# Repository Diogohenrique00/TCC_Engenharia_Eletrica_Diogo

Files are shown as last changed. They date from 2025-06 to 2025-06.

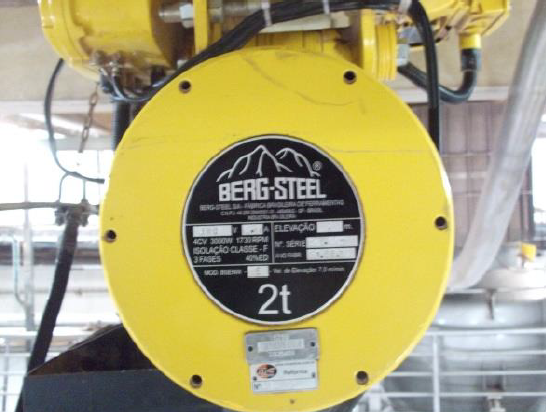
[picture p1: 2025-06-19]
FOTOS TALHAS/Captura de tela 2025-03-13 082055.png

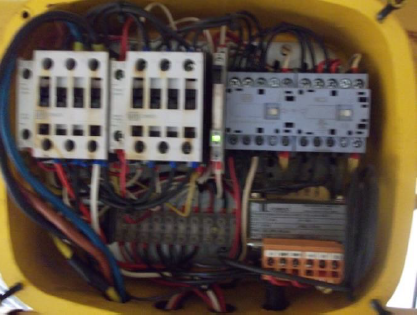
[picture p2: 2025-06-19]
FOTOS TALHAS/Captura de tela 2025-03-13 082145.png

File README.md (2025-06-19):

# ⚡ Instalações de Painéis Elétricos Para Adequação à NR-12 em Equipamentos de elevação de Cargas

Este repositório apresenta um estudo de caso sobre a adequação de painéis elétricos de comando em equipamentos de elevação de cargas, com base nas exigências da NR-12 na indústria alimentícia. A pesquisa teve como objetivo identificar não conformidades no sistema de comando de uma talha elétrica, descrever as intervenções técnicas realizadas e avaliar os indicadores obtidos após a implementação das melhorias.
_____________________________________________________________________________________________________________________________________________________________________________________________________________________
## 📌 Objetivos do Projeto

✅ Analisar o processo de adequação de um equipamento de elevação de cargas à NR-12, com ênfase na instalação e operação de painéis elétricos normatizados e seguros;  
✅ Verificar as principais não conformidades encontradas no sistema de comando e controle anterior;                                                                    
✅ Descrever os procedimentos técnicos e normativos utilizados na adequação dos painéis;                                                                               
✅ Avaliar os indicadores com a implementação, considerando ganhos em segurança, eficiência e desempenho técnico.                                                      
_______________________________________________________________________________________________________________________________________________________________________
## 🔍 Conteúdo Técnico

O trabalho abrange todas as etapas necessárias para garantir a segurança na utilização de máquinas e equipamentos, especificamente em uma talha elétrica:

## 🔌 Dimensionamento Elétrico

- Cálculos elétricos dos motores utilizados;
- Correção de fator por agrupamento e temperatura, conforme a NBR 5410;
- Escolha do disjuntor motor adequado para o projeto.

## ⚠️ Escolha dos dispositivos de segurança, conforme à NR-12

- Relé de segurança;
- Relé falta de fase;
- Disjuntor motor;
- Contator de segurança;
- Fonte chaveada;
- Botão de emergência;
- Chave seccionadora geral.
_____________________________________________________________________________________________________________________________________________________________________________________________________________________
## ⚙️ Descrição do equipamento de elevação de carga

A talha elétrica utilizada no processo é do tipo trifásica 380V, com capacidade nominal de 2 toneladas, acionada por um motor elétrico trifásico 4cv (deslocamento vertical) e um motor elétrico trifásico 0,5cv (locomoção transversal) e controlada por botoeiras pendentes.
_____________________________________________________________________________________________________________________________________________________________________________________________________________________
## 🛠️ Ferramentas Utilizadas

- AutoCAD (layout do painel);
- Excel (cálculos).
_____________________________________________________________________________________________________________________________________________________________________________________________________________________
## 🏫 Instituição
Centro Universitário da Fundação Hermínio Ometto (FHO) – Araras/SP                                                                                                                                                                      
Curso: Engenharia Elétrica                                                                                                                                                                                            
Período de entrega: Junho de 2025
_____________________________________________________________________________________________________________________________________________________________________________________________________________________
## ⚠️ Restrições de Uso

Este projeto destina-se exclusivamente a fins didáticos e não deve ser utilizado em aplicações reais sem validação técnica profissional. Qualquer uso comercial, seja direto ou indireto, é proibido sem autorização expressa do autor. Para outras finalidades ou obrigações de uso que não se enquadrem nessas condições, por favor, entre em contato com o autor.
_____________________________________________________________________________________________________________________________________________________________________________________________________________________
## ✉️ Contato

- Diogo Henrique de Camargo
- diogocamargo91@gmail.com
- https://www.linkedin.com/in/diogo-henrique-a6a4a41b4/

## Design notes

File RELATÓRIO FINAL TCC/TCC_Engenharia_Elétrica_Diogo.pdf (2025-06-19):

INSTALAÇÕES DE PAINÉIS ELÉTRICOS PARA ADEQUAÇÃO À NR-12 EM

EQUIPAMENTOS DE ELEVAÇÃO DE CARGAS EM UMA INDÚSTRIA

ALIMENTÍCIA

Diogo Henrique de Camargo (FHO) diogocamargo@alunos.fho.edu.br Daniel Augusto Pagi Ferreira (FHO) danielferreira@fho.edu.br

Resumo

Este trabalho apresenta um estudo de caso sobre a adequação de painéis elétricos de comando em equipamentos de elevação de cargas, com base nas exigências da NR-12 na indústria alimentícia. A pesquisa teve como objetivo identificar não conformidades no sistema de comando de uma talha elétrica, descrever as intervenções técnicas realizadas e avaliar os indicadores obtidos após a implementação das melhorias. A metodologia adotada foi de natureza qualitativa e aplicada, com abordagem técnico-descritiva, estruturada a partir de levantamento in loco, análise documental, aplicação de checklists normativos e coleta de dados operacionais. Os dispositivos selecionados para o novo painel incluíram relé de segurança, chave seccionadora geral, botão de emergência, sensores magnéticos de fim de curso, fonte chaveada, contator de segurança e disjuntor motor dimensionado conforme a NBR 5410. Os indicadores demonstraram uma eliminação total das falhas elétricas e um aumento de 75% na eficiência da parada de emergência, além de diminuição de 60% no tempo de manutenção corretiva. A adequação também contribuiu para a melhoria da cultura de segurança e preparação da empresa para futuras auditorias e fiscalizações.

Palavras-chave: NR-12; Segurança elétrica; Painel elétrico; Equipamentos de elevação.

### 1. Introdução

A segurança em ambientes industriais constitui um dos principais pilares da engenharia

moderna, especialmente em setores com alta complexidade operacional, como é o caso da

indústria alimentícia. O avanço das tecnologias produtivas e a crescente automatização dos

processos tornaram indispensáveis as ações preventivas voltadas à integridade física dos

trabalhadores. De acordo com dados do Ministério do Trabalho e Emprego, cerca de 25% dos

acidentes mais graves em ambientes industriais no Brasil estão diretamente associados à

utilização de máquinas sem proteção adequada, com falhas de operação e ausência de dispositivos de segurança elétrica e mecânica (SANTOS JÚNIOR; ZANGIROLAMI, 2020).

Nesse cenário, a Norma Regulamentadora nº 12 (NR-12), publicada pela Portaria nº 3.214/1978

e atualizada periodicamente (última versão data de 2022), tem papel central na regulamentação

da segurança do trabalho em máquinas e equipamentos. Seu conteúdo estabelece critérios

técnicos e diretrizes para a instalação, operação, manutenção e desativação de sistemas

mecânicos e elétricos industriais. Desde as reformulações mais significativas realizadas a partir de 2010, a NR-12 passou a adotar uma abordagem preventiva e sistêmica, exigindo a análise

de riscos e a implementação de dispositivos de segurança interligados aos sistemas de comando

(FERREIRA; SOUZA, 2021).
É importante destacar que a NR-12 atua de forma articulada com outras normas técnicas

igualmente essenciais, como a NR-10 — voltada à segurança em instalações elétricas — e a

NBR 5410, que regula a execução de instalações elétricas de baixa tensão. Essa

interdependência normativa exige que profissionais da engenharia tenham domínio transversal

das exigências legais e técnicas, garantindo que o projeto e a instalação de painéis elétricos, por

exemplo, respeitem critérios de proteção contra choques, sobrecargas, curtos-circuitos,

acessibilidade e controle ergonômico (COSTA et al., 2022).

No caso específico da indústria alimentícia, a aplicação da NR-12 apresenta desafios adicionais.

As condições ambientais a que os equipamentos estão submetidos — como presença de

umidade, vapores, poeiras orgânicas e agentes de limpeza — impõem requisitos mais rigorosos

de vedação, resistência e facilidade de higienização. Equipamentos como talhas elétricas e

pontes rolantes, amplamente utilizados na movimentação interna de insumos e produtos,

precisam ser dotados de painéis elétricos que assegurem tanto o funcionamento automatizado

quanto a interrupção imediata em situações de risco (FERNANDES et al., 2024).

A relevância da instalação adequada de painéis elétricos para a segurança dos operadores é

incontestável. Esses dispositivos não apenas comandam o funcionamento do equipamento, mas

integram sistemas de proteção que detectam falhas, bloqueiam movimentos indevidos e evitam

o acionamento em condições inseguras. botões de emergência (figura 2), chaves seletoras, relés

de segurança, fontes chaveadas, sensores magnéticos (figura 1) e dispositivos de

intertravamento formam um conjunto que, quando corretamente dimensionado e instalado,

reduz consideravelmente os riscos de acidentes, paradas não programadas e falhas operacionais

(DRUMOND, 2021; LAMB, 2015).

Figura 1 – Sensor magnético

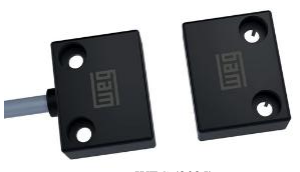
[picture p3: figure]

Fonte: WEG (2025)
Conforme mostra a Figura 2, o botão de parada de emergência é um dos dispositivos

obrigatórios exigidos pela NR-12. Os relés de segurança conforme mostra a figura 3, são previstos para montagem em quadros de comando. Eles servem para a análise segura dos

terminais de ruptura positiva de chaves magnéticas fim de curso, sensores indutivos,

capacitivos, ópticos e contatos de botões de emergência. Quando recebem um sinal elétrico

fechado entre os canais S11-S12 e/ou S21-S22, os contatos de saída 13-14, 23-24 e 33-34

fecham, mediante a atuação da entrada do botão de rearme Y1/Y2. Ao abrir as entradas S11-

S12 e/ou S21-S22, os contatos 13-14, 23-24 e 33-34 abrem, inibindo o funcionamento do

circuito elétrico (FAQUIM, 2015). Esses dispositivos são essenciais para garantir que a energia

seja interrompida de forma imediata e controlada em situações de emergência, atuando como

última barreira contra falhas críticas no sistema.

Figura 2 – Botão de emergência conforme NR-12

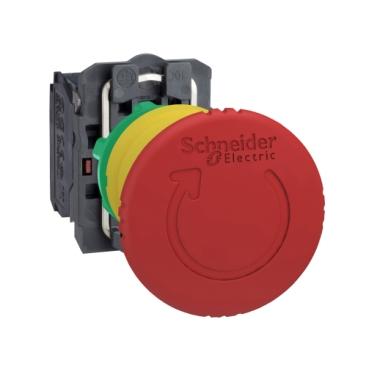
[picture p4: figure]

Fonte: Schneider (2025)

Figura 3 – Relé de segurança parada de emergência

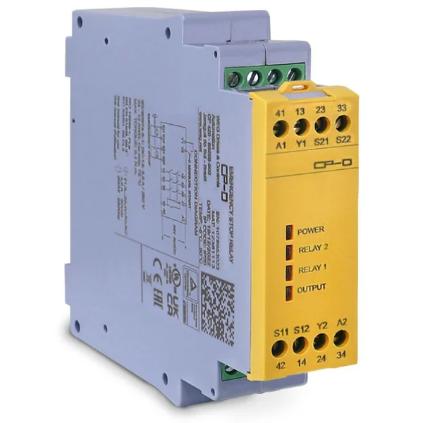
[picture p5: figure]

Fonte: WEG (2025)

No entanto, é comum observar resistência de gestores industriais à implementação plena das

normas técnicas. A percepção de que a adequação representa um custo adicional, e não um

investimento em segurança e eficiência, ainda persiste em diversas organizações. Esse

obstáculo cultural muitas vezes impede a adoção de medidas simples, porém eficazes, como o uso de sistemas de controle em malha fechada, a instalação de botoeiras com rearme em pontos

estratégicos e a atualização dos componentes obsoletos dos painéis (MOURA et al., 2022).

Neste trabalho, busca-se apresentar um estudo de caso real realizado em uma indústria

alimentícia de grande porte, localizada no interior do estado de São Paulo, que enfrentava sérios

problemas de segurança e operacionalidade em seus sistemas de elevação de cargas. O

equipamento em questão — uma talha elétrica utilizada no transporte de insumos entre setores

produtivos — operava sem dispositivos normatizados de controle e proteção, colocando em

risco os trabalhadores e comprometendo a regularidade das atividades produtivas. Com a

intervenção técnica conduzida, foram instalados painéis elétricos de comando e proteção

totalmente compatíveis com as exigências da NR-12, NR-10 e NBR 5410.

A análise do caso permitiu identificar, inicialmente, as principais não conformidades presentes

no sistema antigo, como a inexistência de botão de parada de emergência acessível, ausência

de relé falta de fase, relé de segurança, instalação elétrica desorganizada e fiação exposta. Além

disso, o painel apresentava falhas de vedação e estava posicionado em local de difícil acesso,

contrariando as recomendações da NR-10. A partir dessas constatações, foram definidos os

critérios de intervenção, priorizando-se a segurança elétrica, a ergonomia operacional e a

facilidade de manutenção (FAQUIM, 2015; OLIVEIRA et al., 2023).

Durante a implementação, todos os dispositivos foram cuidadosamente dimensionados

conforme os parâmetros técnicos exigidos, incluindo corrente nominal, proteção térmica e

elétrica, disposição lógica dos componentes, bitolas de condutores e segregação dos circuitos

de comando e potência. A instalação física do novo painel foi precedida por um projeto elétrico

detalhado e pela consulta às instruções dos fabricantes, assegurando a rastreabilidade técnica e

a conformidade documental — outro requisito fundamental da NR-12 (ALMEIDA et al., 2023).

Após a instalação do novo sistema, foi possível observar melhorias significativas na segurança

e na eficiência operacional. A presença de botões de parada de emergência, chaves seletoras de

operação e sensores magnéticos intertravados trouxe maior controle ao processo e reduziu o

tempo de resposta diante de situações críticas. Do ponto de vista organizacional, houve também

maior integração entre os setores de engenharia, manutenção e segurança do trabalho, com

impactos positivos na cultura interna da empresa e na percepção dos trabalhadores quanto ao

valor da segurança (ROCHA et al., 2020).

Diante disso, este trabalho tem como objetivo geral analisar o processo de adequação de um

equipamento de elevação de cargas à NR-12 em uma indústria alimentícia, com ênfase na

instalação e operação de painéis elétricos normatizados e seguros. Os objetivos específicos são:

(i) verificar as principais não conformidades encontradas no sistema de comando e controle anterior; (ii) descrever os procedimentos técnicos e normativos utilizados na adequação dos

painéis; e (iii) avaliar os indicadores com a implementação, considerando ganhos em segurança,

eficiência e desempenho técnico.

### 2. Metodologia

Este trabalho adota uma abordagem qualitativa, de natureza aplicada e caráter descritivo-

exploratório, com foco na análise técnica da adequação de um equipamento de elevação de

cargas à NR-12, por meio da instalação de painéis elétricos em uma indústria alimentícia. A

metodologia foi estruturada a partir de um estudo de caso real, conduzido em ambiente fabril,

e respaldado por normas técnicas brasileiras vigentes.

A coleta de dados foi realizada de forma direta e documental. Inicialmente, foram feitas visitas

técnicas ao local de instalação, com observações in loco das condições do equipamento antes

da adequação. Foram registradas fotografias, esquemas antigos do painel, apontamentos da

equipe de manutenção, e utilizadas fichas de inspeção com base em checklists normativos da

própria NR-12. Além disso, foram consultados manuais dos fabricantes dos dispositivos

elétricos utilizados no projeto, relatórios internos de manutenção e registros de não

conformidades da CIPA. Embora não tenham sido aplicadas entrevistas formais, os operadores

contribuíram informalmente com relatos de falhas recorrentes no equipamento, que foram

incorporados à análise.

Os critérios adotados para análise técnica basearam-se, principalmente, nos requisitos da NR-

12 (segurança em máquinas e equipamentos), da NR-10 (segurança em instalações e serviços

em eletricidade) e da NBR 5410 (instalações elétricas de baixa tensão). A identificação das não

conformidades seguiu parâmetros como: ausência de botão de parada de emergência;

inexistência de relé falta de fase; fiação exposta; ausência de segregação entre comandos e

potência; e inadequação do posicionamento do painel em relação ao operador. Após a

intervenção, foram analisados os novos dispositivos instalados quanto à sua função de

segurança, conformidade normativa, ergonomia e impacto na operação da talha elétrica.

A intervenção técnica foi conduzida pela equipe de manutenção da própria empresa, com apoio

de um engenheiro eletricista, em um processo dividido em etapas: (1) levantamento das falhas

existentes; (2) desenvolvimento do novo projeto técnico do painel elétrico; (3)

dimensionamento e aquisição dos componentes normatizados; (4) instalação física do novo

painel, com testes de funcionamento; e (5) verificação final de conformidade com base na NR-

12. O novo painel instalado passou a contar com chave seccionadora, disjuntores, relé de

segurança, fonte chaveada, botões de emergência e sensores magnéticos. Ao final do processo, foram observados os efeitos da adequação em termos de organização do sistema elétrico,

confiabilidade operacional e segurança do operador, os quais foram comparados com a situação

inicial do equipamento.

### 3. Referencial técnico e normativo

### 3.1. Evolução das Normas de Segurança no Trabalho

Com o avanço da industrialização, a mecanização dos processos produtivos e o crescimento do

número de acidentes de trabalho envolvendo máquinas e equipamentos, tornou-se evidente a

necessidade de normatização mais específica e atualizada sobre a proteção do trabalhador no

ambiente industrial (ROCHA et al., 2020).

Foi nesse contexto que o Ministério do Trabalho, por meio da Portaria nº 3.214, de 8 de junho

de 1978, instituiu as primeiras Normas Regulamentadoras (NRs), criando um conjunto inicial

de 28 normas voltadas à segurança e saúde ocupacional. Essa medida atendeu ao disposto no

artigo 200, inciso VIII da CLT, que determina como uma das atribuições do Estado a

fiscalização das condições de segurança nos ambientes de trabalho. As NRs, desde então,

passaram a integrar o ordenamento jurídico brasileiro com força normativa e caráter de

obrigatoriedade para todas as empresas que operam sob o regime da CLT (FERREIRA;

SOUZA, 2021).

A partir dessa reformulação, a NR-12 passou a ser encarada como uma norma de caráter técnico

e multidisciplinar, exigindo a atuação conjunta de engenheiros de segurança, eletricistas,

projetistas e profissionais da manutenção. De acordo com Moura et al. (2022), a norma adota

uma abordagem preventiva baseada na análise de risco, determinando que todas as etapas do

ciclo de vida da máquina — desde o projeto até a operação — contemplem critérios de

segurança funcional. A inserção de exigências como o uso de relés de segurança, botões de

parada de emergência e rearme manual representa não apenas uma mudança na estrutura técnica

das instalações, mas também na cultura de segurança dentro das organizações.

Importante destacar que a consolidação da NR-12 acompanha um movimento global de

atualização das normas de segurança industrial. No Brasil, isso se reflete na necessidade de

integrar a NR-12 com outras normativas complementares, como a NR-10, que trata da

segurança em instalações elétricas, e a NBR 5410, responsável por estabelecer os critérios

técnicos para instalações elétricas de baixa tensão. Segundo Costa et al. (2022), essa integração

entre normas é fundamental para garantir que painéis elétricos de comando — como os

utilizados em talhas e outros equipamentos de elevação — atendam simultaneamente aos

requisitos de segurança elétrica, ergonomia e operação segura.

### 3.2. A Consolidação da NR-12

A NR-12 passou a ocupar papel central na regulamentação da segurança em máquinas e

equipamentos após as reformulações promovidas pelo Ministério do Trabalho, especialmente a

partir da Portaria MTE nº 197/2010, que conferiu à norma maior detalhamento técnico e

aplicabilidade prática. Com a nova redação, a norma passou a exigir, além da presença física

de dispositivos de segurança, a comprovação documental da conformidade e a realização de

análise de riscos, ampliando a responsabilidade dos empregadores e projetistas (MOURA et al.,

2022).

Entre os principais avanços da norma está a obrigatoriedade de implementação de sistemas de

parada de emergência, dispositivos de intertravamento, relés de segurança, proteção contra

partidas inesperadas, reorganização do layout de painéis elétricos, e requisitos específicos para

acesso seguro a partes móveis. Esses dispositivos devem ser projetados de forma que, em caso

de falha, o sistema elétrico seja automaticamente interrompido, garantindo que a máquina ou

equipamento permaneça em estado seguro até que o risco seja eliminado (FAQUIM, 2015).

A NR-12 também determina que os painéis elétricos sejam instalados em locais acessíveis,

sinalizados, protegidos contra agentes externos e com separação clara entre os circuitos de

comando e potência. Essa exigência está diretamente relacionada à segurança de sistemas que

utilizam equipamentos de elevação, como talhas elétricas, cuja operação envolve risco elevado

em caso de falha de controle. Conforme destaca Fernandes et al. (2024), a ausência de

dispositivos de parada e intertravamento nesses sistemas é uma das principais causas de

acidentes industriais com carga suspensa.

A consolidação da NR-12, portanto, não apenas sistematizou os critérios técnicos de segurança

em máquinas, como também influenciou diretamente o projeto de painéis elétricos

normatizados, voltados à prevenção de falhas e acidentes. Sua aplicação no ambiente industrial

exige conhecimento técnico integrado das normas correlatas, como a NR-10 e a NBR 5410, e

vem sendo cada vez mais demandada por fiscalizações, auditorias internas e certificações de

qualidade.

### 3.3. Relação com a NR-10 e a NBR 5410

A correta aplicação da NR-12 em projetos de adequação de máquinas e equipamentos exige,

obrigatoriamente, a articulação com outras normas técnicas complementares, entre as quais se

destacam a NR-10 e a NBR 5410. Enquanto a NR-12 trata da segurança funcional e mecânica

dos equipamentos, a NR-10 estabelece os requisitos para segurança em instalações e serviços em eletricidade, sendo indispensável para o planejamento, execução e manutenção de painéis

elétricos industriais (COSTA et al., 2022).

A NR-10 exige, por exemplo, que todos os sistemas elétricos sejam projetados com dispositivos

de seccionamento visível, proteção contra contato direto e indireto, identificação dos

condutores, aterramento adequado e localização acessível dos painéis. Além disso, a norma

estabelece que os painéis devem conter sinalização de segurança, dispositivos de proteção

contra sobrecorrente e sobretensão, e organização interna que facilite intervenções seguras,

reduzindo os riscos de choque elétrico e curto-circuito (FERREIRA; SOUZA, 2021).

Já a NBR 5410, publicada pela Associação Brasileira de Normas Técnicas (ABNT),

complementa a NR-10 ao oferecer critérios técnicos precisos para o dimensionamento dos

condutores, definição da seção mínima dos cabos, separação entre circuitos de potência e

comando, e proteção contra falhas elétricas. Essa norma é essencial para garantir a integridade

elétrica dos painéis de comando e o funcionamento seguro dos sistemas de automação.

No caso específico da adequação do painel elétrico da talha analisada neste trabalho, as

exigências dessas normas foram determinantes para a seleção e instalação de disjuntores

termomagnéticos, fontes chaveadas, relés de monitoramento de fase, botões de emergência e

sistemas de rearme manual. A interação entre a NR-12, NR-10 e NBR 5410 assegura que o

sistema funcione dentro dos parâmetros legais, oferecendo proteção tanto ao equipamento

quanto ao operador (DRUMOND, 2021).

Portanto, compreender essa interdependência normativa é fundamental para a elaboração de

projetos elétricos seguros, eficientes e normatizados, como se observa na aplicação prática deste

estudo de caso.

### 4. Estudo de caso

### 4.1. Caracterização da Indústria

O estudo foi realizado em uma grande indústria alimentícia no interior de São Paulo, uma

empresa multinacional que exporta seus produtos para mais de 60 países, sendo considerada a

maior exportadora de café do mundo. Ela preza por 3 principais pilares, sendo, segurança,

qualidade e meio ambiente e investe fortemente na área da segurança, tendo regras rigorosas e

buscando sempre minimizar ao máximo os acidentes ou quase acidentes dentro da fábrica, foi

pensando nisso que surgiu a demanda pela adequação a NR-12 dos equipamentos de elevação

de cargas.

Após um quase acidente que ocorreu com uma das operadoras do equipamento que utilizava o

controle manual para manusear a talha, uma das alças do Bag estourou e por pouco não caiu sobre ela, com isso os gestores juntamente com a equipe de segurança da fábrica decidiram

realizar a melhoria e instalar os painéis de comando, com objetivo de minimizar este

tipo de acidente.

Um dos pontos críticos da planta refere-se à movimentação interna de cargas, realizada por

meio de uma talha elétrica instalada em um sistema de trilhos metálicos, responsável por

transportar sacarias, bombonas e caixas entre os setores de produção e armazenamento. O

equipamento, essencial para o fluxo operacional da empresa, apresentava sérias deficiências em

seu sistema de comando e controle, estando em desacordo com os requisitos mínimos de

segurança da NR-12.

### 4.2. Diagnóstico do Sistema Antes da Adequação

Durante a avaliação inicial, foram constatadas diversas não conformidades no painel elétrico

de comando da talha, entre elas:

− | Ausência de botão de parada de emergência acessível;
− | Falta de relé de monitoramento de fase;
− | Cabos desorganizados e expostos, sem identificação adequada;
− | Painel posicionado em local de difícil acesso;
− | Ausência de segregação entre os circuitos de potência e comando.

Essas deficiências colocavam em risco a integridade física dos operadores e a continuidade do

processo produtivo, configurando violação direta de artigos da NR-12 (itens 12.38 a 12.55),

além da NR-10 e da NBR 5410.

O antigo painel elétrico apresentava irregularidades e ausência de dispositivos de segurança,

conforme mostra a Figura 4.

Figura 4 – Painel elétrico antes da adequação a NR-12

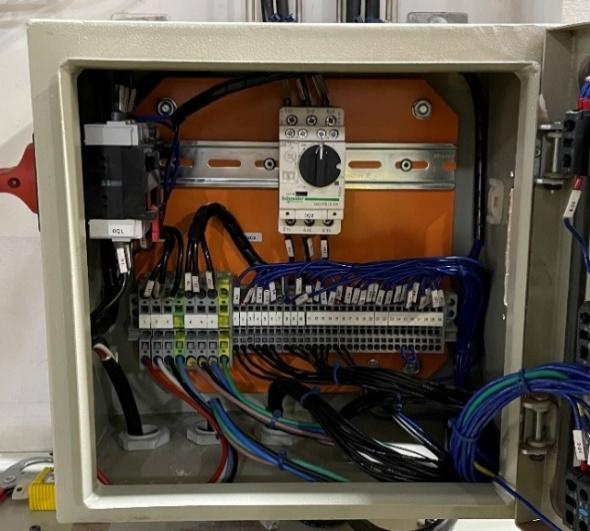
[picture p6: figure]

Fonte: autor

### 4.3. Descrição do Equipamento de Elevação de carga

A talha elétrica utilizada no processo é do tipo trifásica 380V, com capacidade de carga nominal

de 2 toneladas, acionada por motor elétrico trifásico 4cv (deslocamento vertical), um motor

elétrico trifásico 0,5cv (locomoção transversal) e controlada por botoeiras pendentes. A

movimentação horizontal é feita sobre trilho metálico e seu uso é contínuo ao longo dos três

turnos da indústria.

Antes da adequação, o sistema não contava com sensores de fim de curso nem com relé de

segurança. O controle era feito exclusivamente por meio das botoeiras, sem qualquer

intertravamento ou redundância de segurança, conforme mostra a figura 5. O funcionamento

do motor era interrompido apenas manualmente, o que aumentava os riscos de acidentes em

caso de falha humana ou falha elétrica.

Figura 5 – Talha elétrica com controle manual

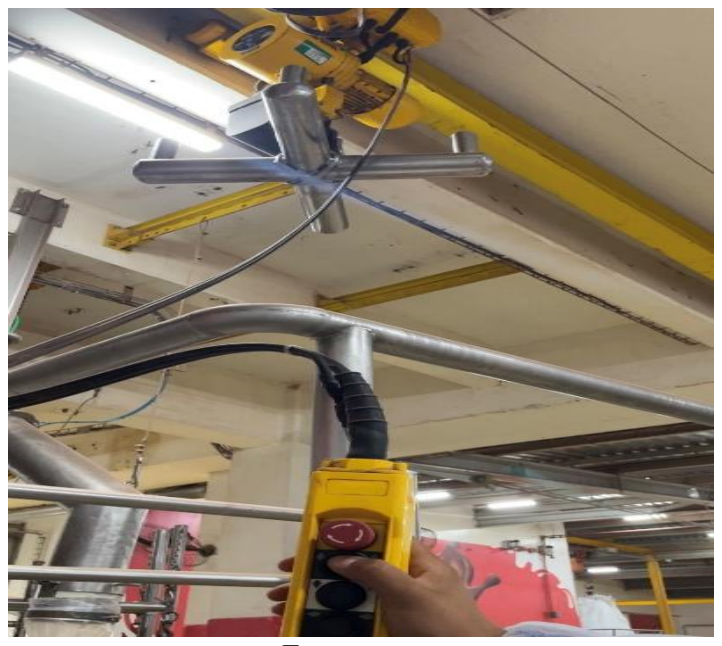
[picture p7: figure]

Fonte: autor

### 4.4. Etapas da Adequação

Com base no diagnóstico realizado, foi elaborado um projeto técnico para substituição do

antigo painel de comando da talha e o controle manual de acionamento, considerando todos os

dispositivos exigidos pela NR-12 e demais normas complementares. O projeto incluiu:

− | Chave seccionadora geral com bloqueio;
− | Relé de monitoramento de fases;
− | Fonte chaveada 24V;
− | Disjuntor termomagnético;
− | Contator de segurança;
− | Relé de segurança com rearme por botoeira;

− | Disjuntor motor;
− | Botões de parada de emergência duplo canal;
− | Régua de bornes, organização interna e identificação.

A nova disposição dos dispositivos conforme mostra a figura 6, garantiu ergonomia,

acessibilidade e segurança operacional. A fiação foi reorganizada com etiquetas de identificação

para melhor visualização e separação dos circuitos de potência e comando. O painel passou a

ser instalado em local visível, com altura adequada, distanciamento adequado e proteção contra

poeira e umidade, conforme exigido pela NR-10. As figuras 7 e 8 mostram o painel elétrico

finalizado e instalado no local seguro, distante da carga em movimento, proporcionando maior

segurança e conforto ao operador.

Figura 6 – Layout painel elétrico conforme NR-12

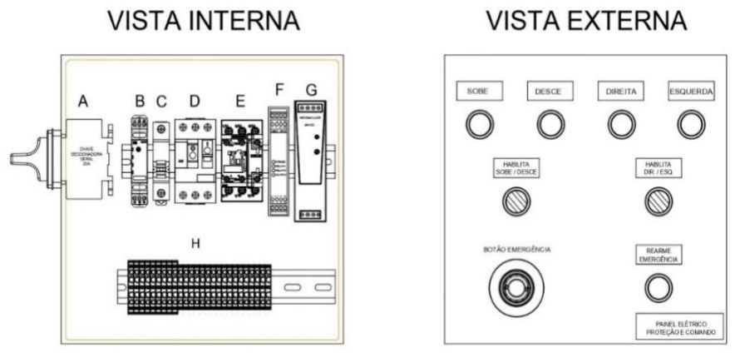
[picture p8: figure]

Fonte: autor

Figura 7 – Painel elétrico conforme NR-12

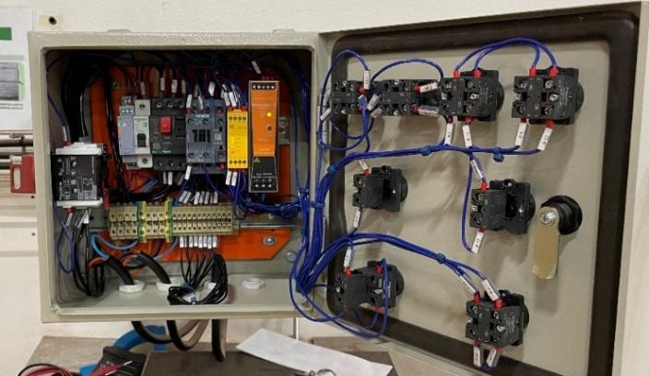
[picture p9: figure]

Fonte: autor

Figura 8 – Painel elétrico conforme NR-12

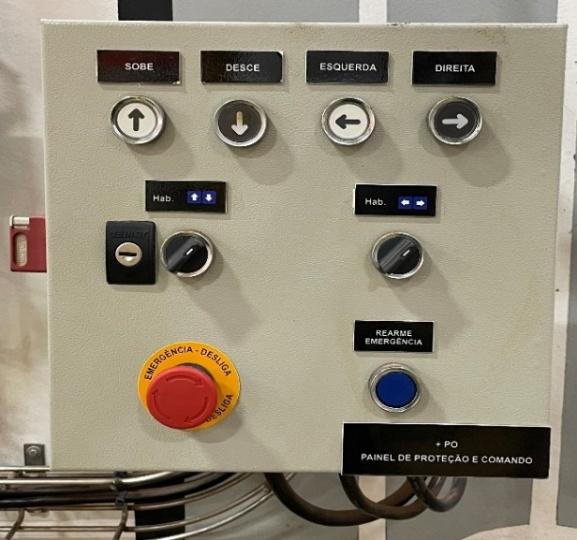
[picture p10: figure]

Fonte: autor

Quadro 1 - Descrição dos componentes do painel elétrico

Identificação | Componente | Fabricante | Função
A | Chave
| seccionadora geral | Schneider | Interromper o fluxo de corrente elétrica do
| | | circuito

B

Relé | de
| monitoramento de
| fases | WEG | Interromper o funcionamento do circuito
| | | elétrico quando ocorrer uma falha ou falta
| | | de fase
C | Disjuntor
| termomagnético
| monopolar | Schneider | Atua na proteção contra curto circuito e
| | | sobrecarga do sistema
D | Disjuntor motor | Schneider | Atua na proteção contra curto circuito e
| | | sobrecarga do sistema, especificamente ao
| | | motor

E

Contator | de
| segurança | Schneider | Dispositivo eletromecânico que realiza a
| | | comutação dos contatos de potência,
| | | energizando o circuito
F | Controle de parada
de | emergência
| (CP-D) | WEG | Dispositivo de segurança que permite o
| | | acionamento apenas quando receber um
| | | sinal de contato fechado nas entradas S11-
| | | 12, S21-22

G

Fonte | chaveada
| 24Vcc | Weidmüller | Converte a tensão de corrente alternada
| | | (220Vca) em corrente contínua (12Vcc ou
| | | 24Vcc)
H | Régua de bornes | Weidmüller | Dispositivo que permite a conexão dos
| | | cabos e fios do circuito
Fonte: autor

### 4.5. Funcionamento dos Relés de Segurança

No novo sistema, destaca-se a instalação de relés de segurança, fundamentais para garantir a

interrupção automática do funcionamento da talha em situações de risco. Esses dispositivos

foram configurados para operar com sensores magnéticos de fim de curso e botoeiras de

emergência, conforme especificado por Faquim (2015).

Os relés de segurança utilizados neste projeto têm a função de monitorar, de forma segura e

contínua, os sinais provenientes de dispositivos de proteção, como sensores de fim de curso,

botões de emergência e chaves magnéticas com ruptura positiva. Instalados no painel de

comando, esses relés operam por meio de dois canais de entrada que, ao receberem um sinal de

fechamento (como entre os terminais S11-S12 ou S21-S22), ativam os contatos de saída (13-

14, 23-24 e 33-34), permitindo o funcionamento do circuito. A liberação do sistema, no entanto,

só ocorre após o acionamento manual da entrada através do botão de rearme (Y1/Y2),

garantindo que a reinicialização do equipamento seja feita de forma intencional e segura. Se

qualquer uma das entradas for interrompida, os contatos são automaticamente abertos,

desativando o circuito e prevenindo riscos ao operador (FAQUIM, 2015).

A lógica de operação do sistema passou a respeitar os requisitos de segurança funcional,

garantindo que a talha só opere em condições seguras, com rearme manual e parada imediata

em situações de emergência.

### 5. Especificações técnicas do projeto

O projeto de adequação do painel elétrico da talha utilizada na indústria alimentícia foi

desenvolvido com base nas exigências das normas NR-12, NR-10 e NBR 5410, contemplando

desde o dimensionamento da instalação elétrica até a escolha dos dispositivos de proteção e

comando. A seguir, apresentam-se os cálculos elétricos dos motores utilizados e as

especificações técnicas adotadas no projeto, com seus respectivos parâmetros normativos.

### 5.1. Motor Principal da Talha Elétrica

Foram utilizados motores de indução trifásicos da WEG, cuja folha de dados é apresentada na

Figura 9.A corrente do motor é calculada a partir de:

I =

Pn
√3Vffcos(φ)η

Onde I é a corrente de projeto do circuito (em A), Pn é a potência nominal do circuito (em W),

Vff é a tensão entre fases (em Vrms), cosφ é o fator de potência e η é o rendimento do motor;

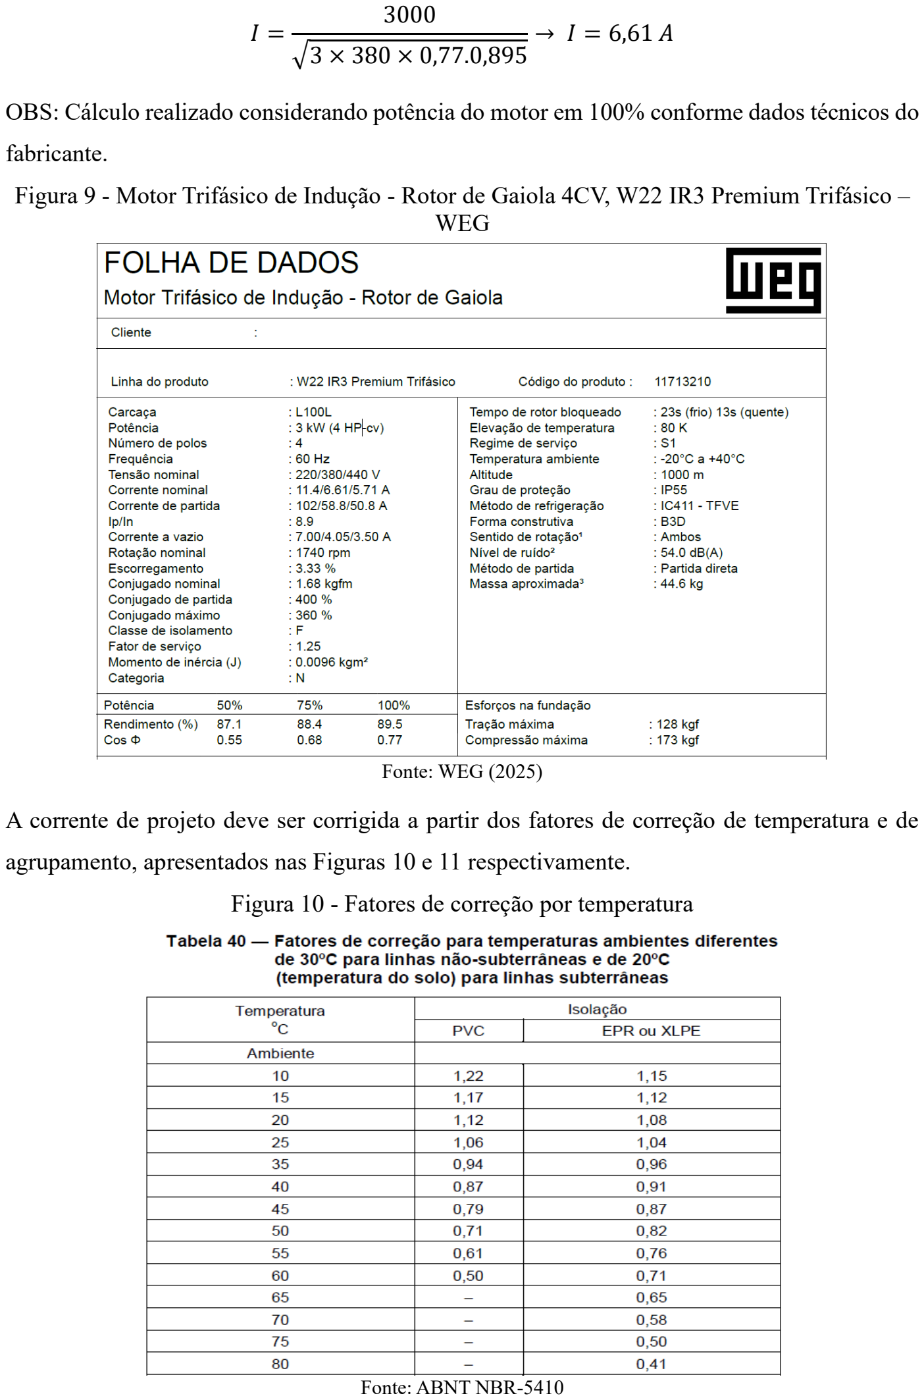
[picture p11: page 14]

I =

3000
√3 × 380 × 0,77.0,895

→ I = 6,61 A

OBS: Cálculo realizado considerando potência do motor em 100% conforme dados técnicos do

fabricante.

Figura 9 - Motor Trifásico de Indução - Rotor de Gaiola 4CV, W22 IR3 Premium Trifásico – WEG

Fonte: WEG (2025)

A corrente de projeto deve ser corrigida a partir dos fatores de correção de temperatura e de

agrupamento, apresentados nas Figuras 10 e 11 respectivamente.

Figura 10 - Fatores de correção por temperatura

Fonte: ABNT NBR-5410

Figura 11 - Fatores de correção por agrupamento

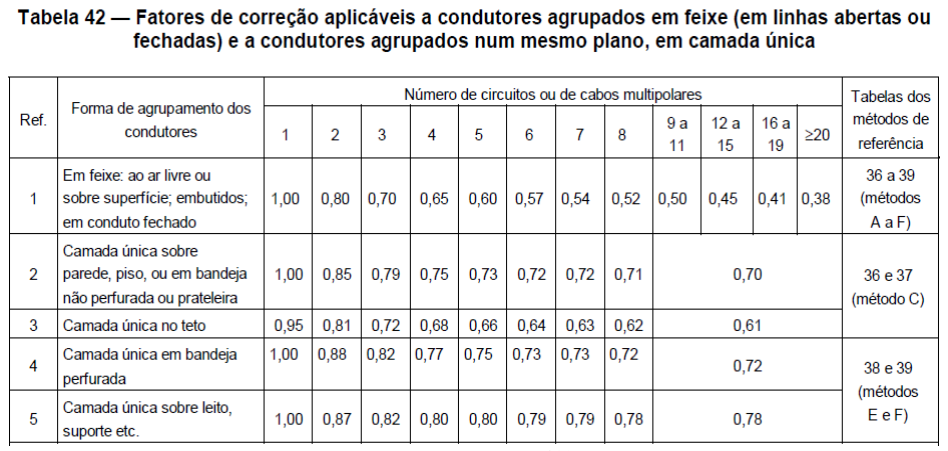
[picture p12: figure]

Fonte: ABNT NBR-5410

I

′ =

I
FCT. FCA

em que I é a corrente do projeto calculada, FCT é o fator de correção por temperatura e FCA é

o fator de correção por agrupamento. O método escolhido foi o tipo E (multipolar) e a corrente

corrigida é:

I1

′ =

6,61
1 × 0,87

→ I1

′ = 7,59 A

### 5.3. Motor trole (carro) da talha

Para a locomoção transversal da talha elétrica foi utilizado o motor trifásico de indução da

WEG, conforme mostra a figura 12. A corrente deste motor é:

I2 =

370
√3 × 380 × 0,7 × 0,782

→ I2 = 1,02 A

Aplicando-se os fatores de correção:

I2

′ =

1,02
1 × 0,87

→ I2

′ = 1,17 A

A corrente total do projeto será de 8,76 A (I1

′ + I2

′
).

O correto dimensionamento da corrente de projeto é de extrema importância, pois desta forma

garantimos que o projeto elétrico será executado de forma segura e que os cabos e disjuntores

não sobreaqueçam ou apresentem falhas que podem levar a acidentes elétricos graves.

Figura 12 - Motor Trifásico de Indução - Rotor de Gaiola 0,5CV, W22 IR3 Premium Trifásico

– WEG

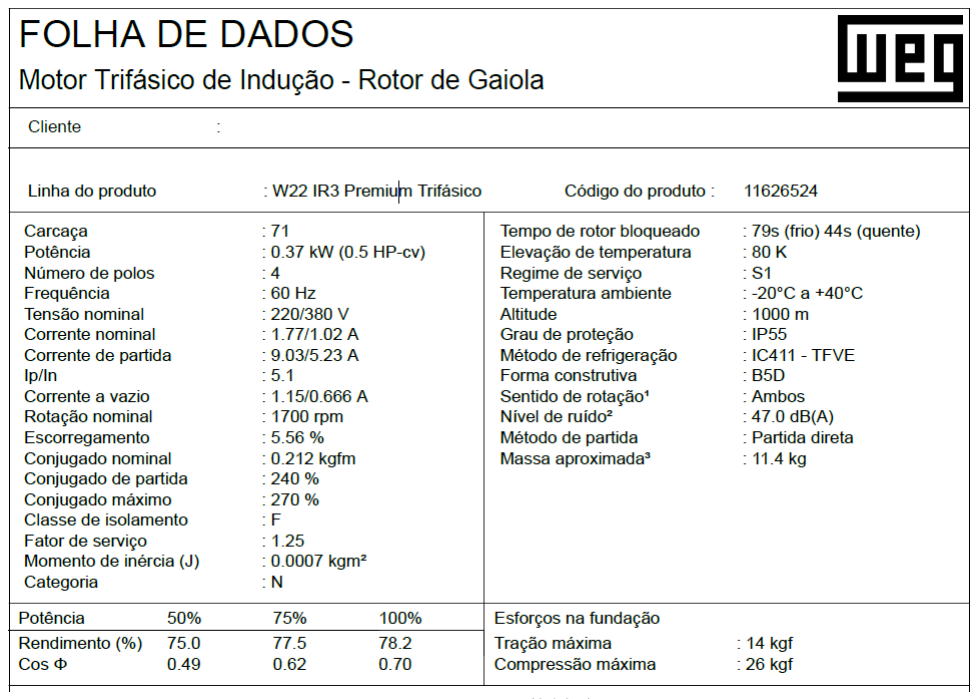
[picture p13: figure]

Fonte: WEG (2025)

### 5.4. Dispositivo de proteção contra sobrecarga e curto-circuito

Para a escolha correta do dispositivo de proteção contra sobrecarga e curto-circuito do projeto,

adotamos como base os valores de corrente encontrados nas equações 1.1 e 2.1.

Portando o dispositivo utilizado foi o disjuntor motor termomagnético da Schneider, conforme

mostra a figura 13.

Figura 13 - Disjuntor motor termomagnético Tesys Deca 6-10A botão de impulsão

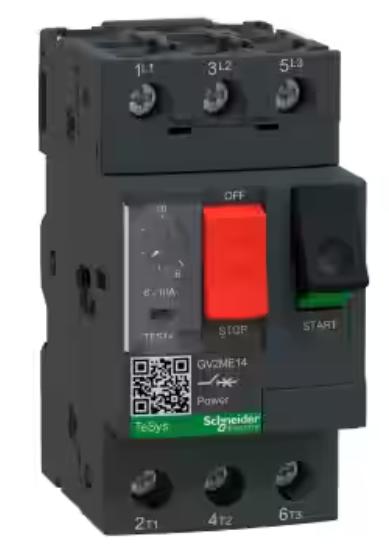
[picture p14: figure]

Fonte: Schneider (2025)

### 6. Resultados e discussão

A adequação do painel elétrico da talha de elevação analisada neste estudo gerou impactos

mensuráveis e significativos na segurança e na operação do equipamento. Os efeitos após a

implementação dos dispositivos normatizados demonstram ganhos objetivos de desempenho,

além de avanços qualitativos na cultura de segurança da empresa.

### 6.1. Dados Quantitativos de Melhoria

Antes da adequação, registrava-se uma média de 2 falhas operacionais por mês relacionadas ao

comando elétrico da talha, como partidas indevidas, desligamentos não intencionais e

travamento do sistema. Após a instalação do novo painel, o número de falhas caiu para zero

ocorrências em um período de 4 meses consecutivos, conforme registros da equipe de

manutenção. Esse dado indica a eliminação completa das falhas de origem elétrica no

equipamento em questão.

No que se refere à segurança, foi observado que o tempo médio de resposta do sistema de parada

emergencial caiu de aproximadamente 3,2 segundos (com acionamento manual direto) para

menos de 0,8 segundo com a utilização do relé de segurança intertravado com o botão de

emergência e os sensores magnéticos. Esse efeito representa um aumento de 75% na agilidade

da parada de emergência, o que reduz drasticamente o risco de acidentes.

Do ponto de vista econômico, a empresa relatou uma redução de 60% no tempo médio de

manutenção corretiva do equipamento, devido à melhor organização interna do painel,

identificação dos circuitos e confiabilidade dos componentes. Isso impacta diretamente na

disponibilidade do equipamento, reduzindo paradas não programadas e otimizando o fluxo

operacional da linha de produção.

### 6.2. Análise Crítica e Comparações Técnicas

Os indicadores obtidos estão em consonância com a literatura técnica que aponta benefícios

expressivos da aplicação da NR-12 em sistemas industriais. Em estudo semelhante, Drumond

(2021) relatou uma redução de 75% em falhas elétricas após a instalação de relés de segurança

em uma linha de envasamento industrial. Já Costa et al. (2022) destacaram que a reorganização

de painéis elétricos conforme a NBR 5410 aumenta a eficiência da manutenção e reduz em até

50% o tempo de diagnóstico de falhas.

A experiência documentada neste trabalho avança ao aplicar esses princípios em um contexto

específico e real de elevação de cargas, dentro do setor alimentício — um ambiente que exige

não apenas segurança elétrica, mas também cuidados com higiene, ergonomia e operação contínua. O uso combinado de relé de segurança, sensores magnéticos e reset manual, com

integração direta ao sistema de comando da talha, demonstrou ser eficaz e replicável em outras

indústrias com infraestrutura similar.

Diante da ausência de informações oficiais, busquei complementar minha análise por meio de

conversas informais com operadores e eletricistas do setor. Onde os mesmos relataram um único

evento relevante ocorrido há aproximadamente três anos, um bag onde se armazenava insumos

de fabricação teve uma de suas alças rompidas, ocasionando um quase acidente em uma das

operadoras do equipamento. Em resposta a esse incidente, os gestores juntamente com a equipe

de segurança optaram por eliminar os controles manuais das talhas e implementar painéis

elétricos, com o objetivo de manter o operador fora da zona de risco durante a movimentação

das cargas.

### 7. Considerações finais

Este trabalho teve como objetivo analisar e aplicar a adequação de um painel elétrico conforme

os requisitos da NR-12, com foco na segurança de um equipamento de elevação de cargas em

uma indústria alimentícia. A partir de um estudo de caso real, foi possível identificar falhas

críticas no sistema anterior, aplicar soluções técnicas compatíveis com as normas vigentes e

verificar, de forma objetiva, os ganhos decorrentes da intervenção.

A substituição do painel elétrico, acompanhada da instalação de dispositivos normatizados

como relé de segurança, sensor magnético de fim de curso, botão de parada de emergência e

reorganização dos circuitos, resultou em redução de 100% nas falhas operacionais elétricas e

em aumento de 75% na eficiência de resposta em situações de emergência. Esses indicadores

quantitativos demonstram que a aplicação das normas técnicas não apenas promove segurança,

mas também gera impactos positivos na eficiência e confiabilidade do processo produtivo.

Além dos indicadores técnicos, o projeto contribuiu para o fortalecimento da cultura de

segurança interna, com mudanças nos procedimentos operacionais e maior envolvimento da

equipe de manutenção e operação. A adequação também prepara a empresa para atender

fiscalizações, auditorias e processos de certificação, com documentação completa e

conformidade normativa assegurada.

As contribuições deste trabalho incluem não apenas a validação técnica do projeto, mas também

a sua viabilidade prática, oferecendo um modelo replicável para empresas que enfrentam

desafios semelhantes com equipamentos antigos e não conformes. A integração entre as normas

NR-12, NR-10 e NBR 5410 foi essencial para alcançar os objetivos centrais do projeto.

Como proposta para trabalhos futuros, recomenda-se a análise de impacto financeiro

comparativo entre a situação anterior e posterior à adequação, bem como a exploração de

recursos de monitoramento remoto, integrando o painel a soluções de automação e controle

baseadas na Indústria 4.0.

Com base nos dados levantados, nas normas aplicadas e nas melhorias observadas, conclui-se

que os objetivos do trabalho foram plenamente atingidos, com contribuição técnica relevante

para o campo da segurança em instalações industriais.

Segue o link do GitHub com todos os arquivos pertinentes para a elaboração do Trabalho

de Conclusão de Curso: https://github.com/Diogohenrique00/TCC_Engenharia_Eletrica_Diog

o. (https://github.com/Diogohenrique00/TCC_Engenharia_Eletrica_Diogo)

REFERÊNCIAS

ALMEIDA, J. C. de et al. Painel de comando elétrico: proposta de padronização e aplicação dos requisitos de segurança com base na NR-12. 2023. Disponível em: https://www.researchgate.net/publication/371182828_Painel_de_comando_eletrico_proposta_de_padronizacao_e_aplicacao_dos_requisitos_d e_seguranca_com_base_na_NR-12. Acesso em: 15 mar. 2025.

COSTA, M. H. da et al. Aplicação das normas NR-10, NR-12 e NBR5410 em painéis elétricos industriais. 2022. Disponível em: https://www.researchgate.net/publication/360185366_Aplicacao_das_normas_NR-10_NR-12_e_NBR5410_em_paineis_eletricos_industriais. Acesso em: 15 mar. 2025.

DRUMOND, Bruno. Painel NR-12: normas e especificações para painéis elétricos. 2021. Disponível em: https://adequada.eng.br/painel-eletrico-nr-12/. Acesso em: 21 mar. 2025.

FAQUIM, Thiago Rabelo. Adequação elétrica e de segurança do quadro de comando de dois transportadores helicoidais de uma indústria alimentícia. 2015. 26 f. Trabalho de Conclusão de Curso (Graduação) – Curso de Tecnologia em Manutenção Industrial, Universidade Tecnológica Federal do Paraná, Medianeira, 2015. Disponível em: https://repositorio.utfpr.edu.br/jspui/bitstream/1/13630/1/adequaçãoelétricasegurança_transportadores.pdf. Acesso em: 21 mar. 2025.

FERNANDES, J. A. et al. Avaliação de riscos para conformidade com a NR-12 em uma envasadora de produtos alimentícios. 2024. Disponível em: https://www.researchgate.net/publication/370088789_Avaliacao_de_riscos_para_conformidade_com_a_NR-12_em_uma_envasadora_de_produtos_alimenticios. Acesso em: 15 mar. 2025.

FERREIRA, R. L.; SOUZA, P. A. Análise de riscos em máquinas e equipamentos industriais conforme NR-

### 12 e ISO 12100. 2021. Disponível em:

https://www.researchgate.net/publication/364415117_Analise_de_Riscos_em_Maquinas_e_Equipamentos_Industriais_Conforme_NR-12_e_ISO_12100. Acesso em: 15 mar. 2025.

LAMB, Frank. Automação industrial na prática. São Paulo: Amgh Editora, 2015. 354 p.

MOURA, V. C. et al. Aplicação da NR-12 na adequação de máquinas e equipamentos na indústria metalúrgica. 2022. Disponível em: https://www.researchgate.net/publication/359453770_Aplicacao_da_NR-12_na_adequacao_de_maquinas_e_equipamentos_na_industria_metalurgica. Acesso em: 15 mar. 2025.

OLIVEIRA, D. R. de et al. Desenvolvimento de um protocolo para avaliação de segurança em conformidade com a NR-12. 2023. Disponível em:

https://www.researchgate.net/publication/365839014_Desenvolvimento_de_um_Protocolo_para_Avaliacao_de_Seguranca_em_Conformidade_com_a_NR-12. Acesso em: 15 mar. 2025.

ROCHA, T. F. et al. Estudo de adequação à NR-12 em esteira transportadora de uma indústria de alimentos. 2020. Disponível em: https://www.researchgate.net/publication/359147979_Estudo_de_Adequacao_a_NR-12_em_Esteira_Transportadora_de_Uma_Industria_de_Alimentos. Acesso em: 15 mar. 2025.

SANTOS JUNIOR, Joubert Rodrigues dos; ZANGIROLAMI, Márcio José. NR-12 - Segurança em máquinas equipamentos conceitos aplicações. 2. ed. São Paulo: Érica, 2020. 369 p.

SCHNEIDER. Botão de emergência conforme NR-12. Disponível em: https://www.se.com/br/pt/product/XB5AS8444/bot%C3%A3o-%C3%B822mm-pl%C3%A1sticoemerg%C3%AAncia-girar-para-destravar-cogumelo-%C3%B840mm-vermelho-2nf/. Acesso em: 20 mai. 2025.

WEG. Relé de segurança parada de emergência. Disponível em: https://www.weg.net/catalog/weg/BR/pt/Seguran%C3%A7a-de-M%C3%A1quinas%2C-Sensores-Industriais-e-Fontes-de-Alimenta%C3%A7%C3%A3o/Seguran%C3%A7a-de-M%C3%A1quinas/Rel%C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. Acesso em: 23 abr. 2025.

WEG. Sensor magnético. Disponível em: https://www.weg.net/catalog/weg/BR/pt/Seguran%C3%A7a-de-M%C3%A1quinas%2C-Sensores-Industriais-e-Fontes-de-Alimenta%C3%A7%C3%A3o/Seguran%C3%A7a-de-M%C3%A1quinas/Senso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. Acesso em: 23 abr. 2025.

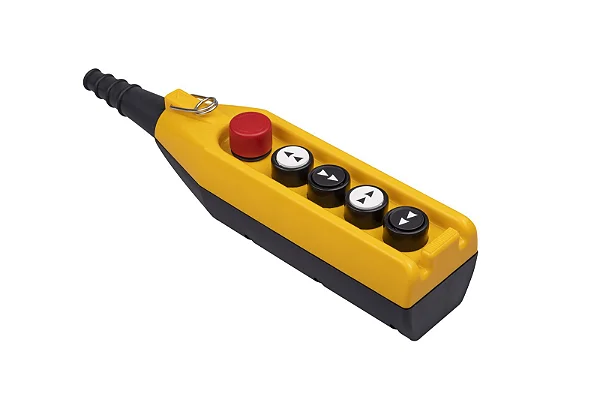
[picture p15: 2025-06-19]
FOTOS TALHAS/SISTEMA ANTIGO TALHA.webp

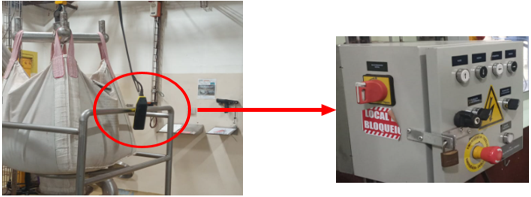
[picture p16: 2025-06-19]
FOTOS TALHAS/Imagem1.png

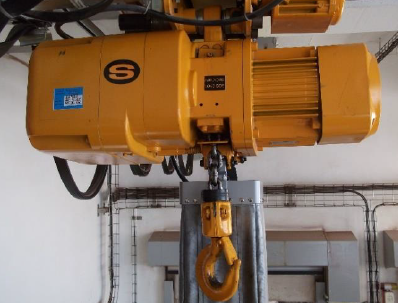
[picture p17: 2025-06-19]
FOTOS TALHAS/Captura de tela 2025-03-13 082923.png

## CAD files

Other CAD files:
COMPONENTES PAINEL ELÉTRICO/CHAVE SECCIONADORA.dwg
LAYOUT PAINÉIS ELÉTRICOS TALHAS/PAINÉIS ELÉTRICOS TALHAS.dwg
COMPONENTES PAINEL ELÉTRICO/RELÉ FALTA DE FASE.dwg
COMPONENTES PAINEL ELÉTRICO/CHAVE SELETORA.dwg
COMPONENTES PAINEL ELÉTRICO/BOTÃO PULSO.dwg
COMPONENTES PAINEL ELÉTRICO/BOTÃO EMERGÊNCIA.dwg
COMPONENTES PAINEL ELÉTRICO/ETIQUETA CIRCULAR EMERGÊNCIA.dwg
COMPONENTES PAINEL ELÉTRICO/FONTE CHAVEADA.dwg
COMPONENTES PAINEL ELÉTRICO/DISJ MOTOR.dwg
COMPONENTES PAINEL ELÉTRICO/PAINEL ELÉTRICO TALHAS.dwg
COMPONENTES PAINEL ELÉTRICO/DISJ MONOPOLAR.dwg

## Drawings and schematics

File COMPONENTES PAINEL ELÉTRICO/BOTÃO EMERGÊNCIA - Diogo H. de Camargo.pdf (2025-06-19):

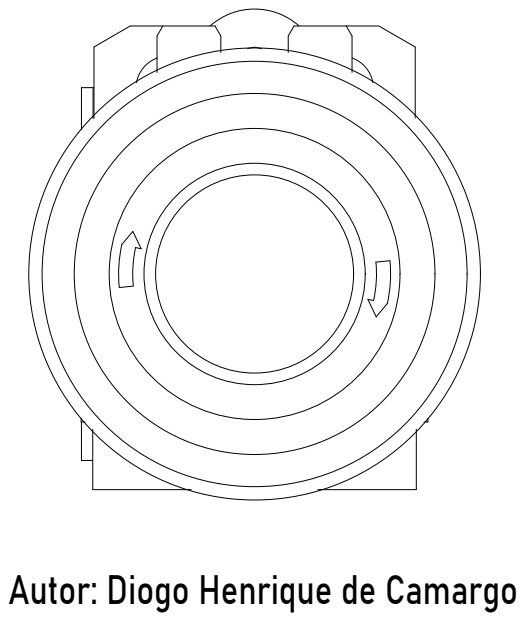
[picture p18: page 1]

Autor: Diogo Henrique de Camargo

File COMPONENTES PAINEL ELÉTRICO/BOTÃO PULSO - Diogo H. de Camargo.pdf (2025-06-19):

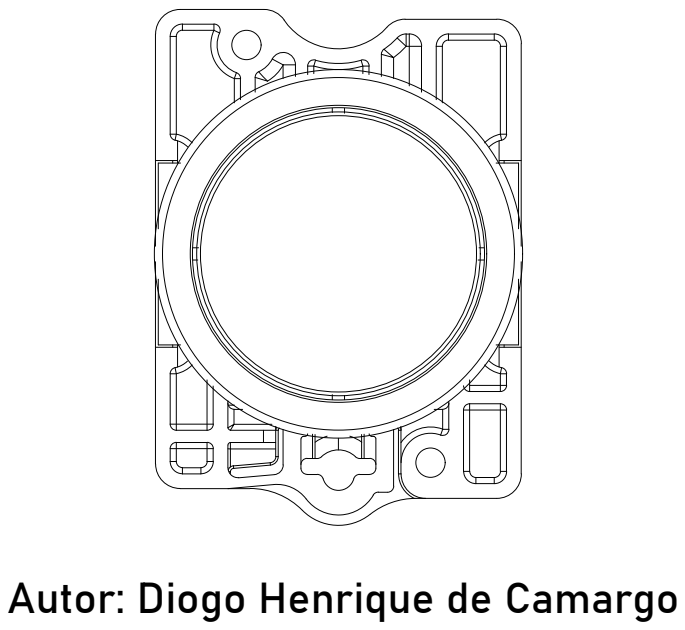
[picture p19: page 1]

Autor: Diogo Henrique de Camargo

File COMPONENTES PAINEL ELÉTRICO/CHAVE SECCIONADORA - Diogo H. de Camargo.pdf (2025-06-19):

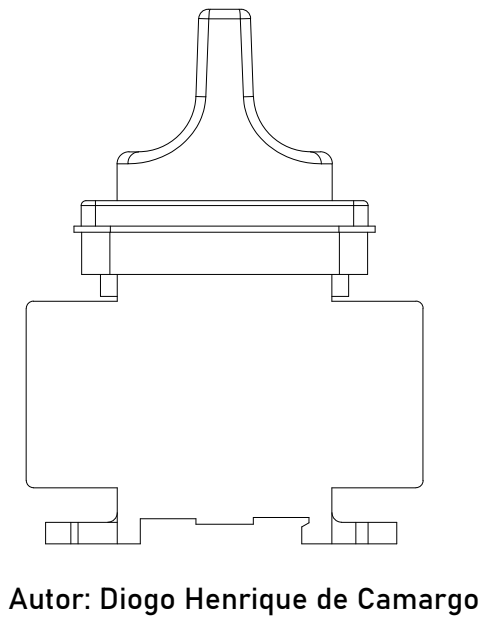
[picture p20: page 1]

Autor: Diogo Henrique de Camargo

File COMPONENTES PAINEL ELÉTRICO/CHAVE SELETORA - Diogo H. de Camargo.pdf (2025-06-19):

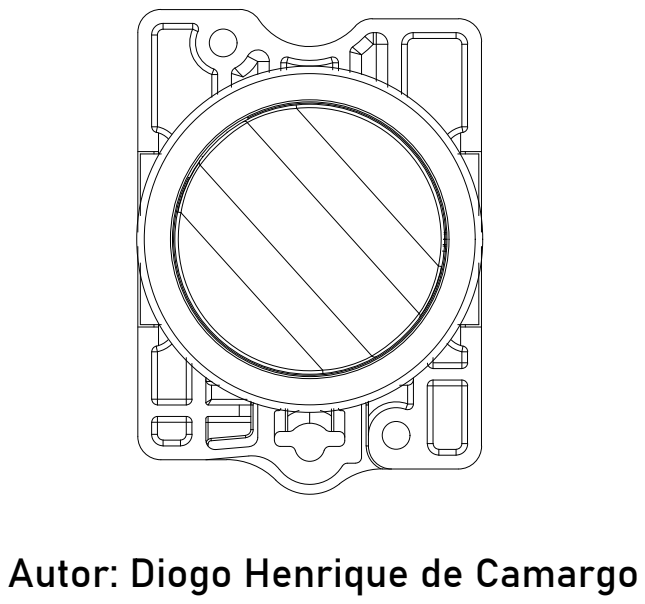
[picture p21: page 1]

Autor: Diogo Henrique de Camargo

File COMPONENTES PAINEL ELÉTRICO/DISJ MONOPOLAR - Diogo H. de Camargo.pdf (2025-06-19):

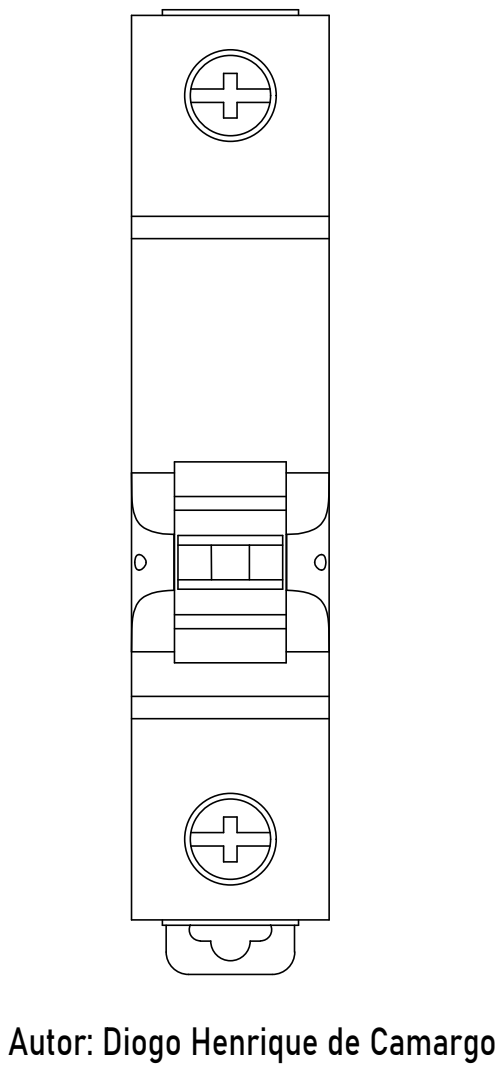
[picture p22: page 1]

Autor: Diogo Henrique de Camargo

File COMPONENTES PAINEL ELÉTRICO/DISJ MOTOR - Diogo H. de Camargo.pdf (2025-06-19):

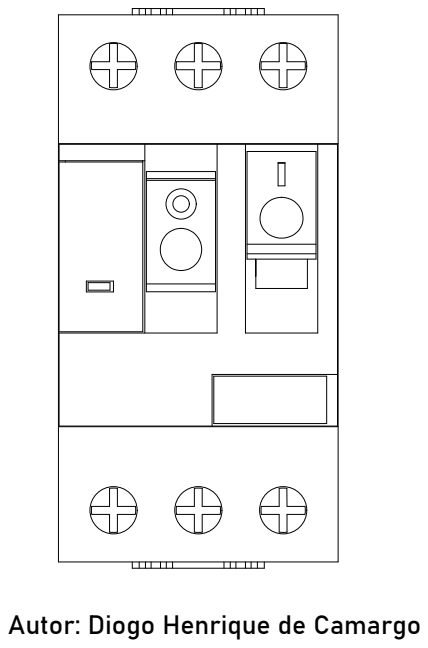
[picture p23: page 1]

Autor: Diogo Henrique de Camargo

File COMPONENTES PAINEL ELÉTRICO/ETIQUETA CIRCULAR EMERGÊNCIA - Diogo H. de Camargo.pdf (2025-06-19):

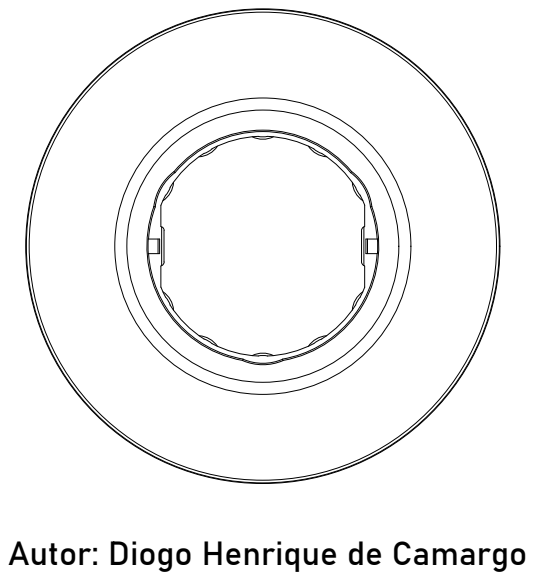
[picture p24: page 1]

Autor: Diogo Henrique de Camargo

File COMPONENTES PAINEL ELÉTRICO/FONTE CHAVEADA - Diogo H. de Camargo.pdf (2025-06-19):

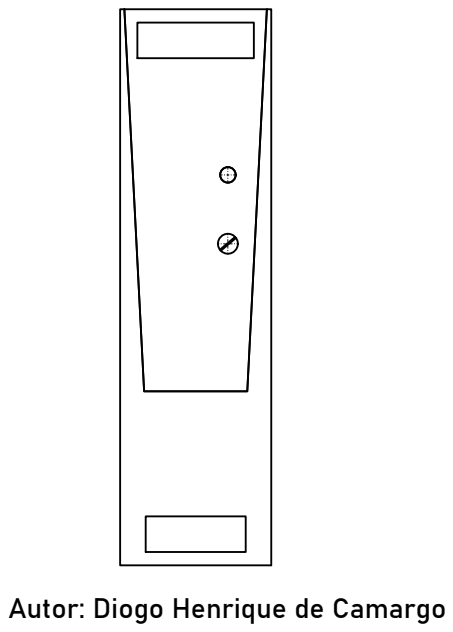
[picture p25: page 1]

Autor: Diogo Henrique de Camargo

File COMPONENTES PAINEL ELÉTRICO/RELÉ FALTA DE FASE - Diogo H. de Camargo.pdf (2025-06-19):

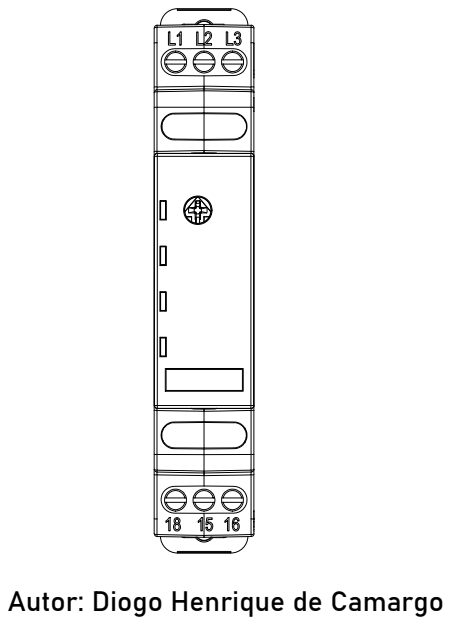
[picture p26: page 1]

Autor: Diogo Henrique de Camargo
